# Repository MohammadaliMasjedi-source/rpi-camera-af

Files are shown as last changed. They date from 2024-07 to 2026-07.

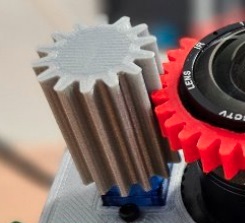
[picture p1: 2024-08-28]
Device setup/Mount the Motor gear.jpg

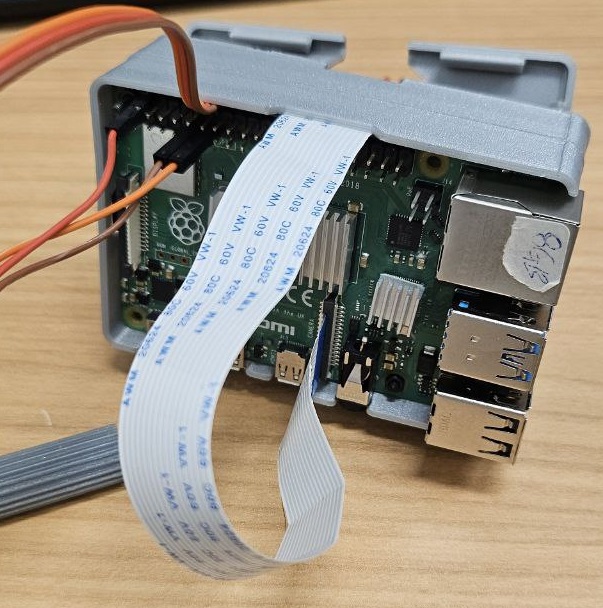
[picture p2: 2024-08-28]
Device setup/Connect the jumper wire to the desire GPIO pins.jpg

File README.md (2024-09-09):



# RPI-Camera-AF
## Auto Focus Camera using Raspberry Pi, Lens, and a Servo Motor

### Overview
The RPI-Camera-AF project leverages the versatile Raspberry Pi platform to create a modular camera system capable of automatic focusing. This innovative setup utilizes a combination of a high-quality lens, a precise servo motor, and custom 3D-printed components, orchestrated by the powerful Raspberry Pi 4 to enhance image clarity dynamically.

## Abstract
This project aimed to design and develop a modular camera platform using a Raspberry Pi, integrating various components such as a camera sensor, a wide lens, an FS90R servo motor, and 3D-printed gears. The primary objective was to create an autofocus mechanism that dynamically adjusts focus by calculating the Laplacian variance of live frame previews to achieve optimal sharpness. The methodology involved assembling the hardware components, programming the Raspberry Pi to control the servo motor based on image sharpness metrics, and enabling real-time focus adjustments. Initial tests demonstrated that while the system could effectively identify and adjust to changes in frame sharpness, limitations related to the precision of the lens's focal point, the quality of the sensor, and the accuracy of the servo motor control were identified. These factors affected the overall efficacy of the autofocus system. The project concluded that while the prototype showed potential, enhancements in hardware precision and control algorithms are necessary for practical applications. Future work will focus on refining these elements to improve system reliability and performance.

## Materials and Methods
In this project, we employed several hardware components and software tools to build our modular camera system. The core of our setup was the **Raspberry Pi 4**, a powerful model with sufficient processing capabilities for image handling and device control. This microcontroller was chosen for its robust support and the ability to interface with various peripherals via its GPIO (General Purpose Input/Output) pins.

### Hardware Components:
- **Raspberry Pi 4**: Serves as the processing unit and control hub.
- **Camera Sensor**: Connects to the Raspberry Pi via the 2-lane MIPI CSI camera port for capturing high-quality images.
- **FS90R Servo Motor**: Compact and lightweight, this motor adjusts the camera lens's focus, interfacing with the Raspberry Pi's GPIO pins.
- **3D-Printed Gears**: One gear mounted on the camera lens and the other on the servo motor to mesh perfectly and enable precise focus adjustments.

### Software Tools:
- **OpenCV (CV2)**: Used for real-time image processing, including calculating the Laplacian variance to determine image sharpness.
- **PiCamera 2 Library**: Designed for interfacing with the Raspberry Pi's camera module to capture and manipulate images directly.
- **RPi.GPIO Library**: Manages the GPIO pins for servo motor control, providing necessary instructions based on the image processing results.

### Assembly Process:
The assembly process involved carefully integrating these components. We started by connecting the camera sensor to the Raspberry Pi via the MIPI CSI port and setting up the servo motor via the GPIO pins. Next, the gears were attached—one on the lens and the other on the servo motor. We positioned the motor close enough to the lens so that the gears could engage correctly to transfer motion from the motor to the lens. This setup ensured that when the motor activated, the lens would rotate to adjust focus based on our software analysis. This methodical assembly ensured all parts worked in harmony, allowing for precise control and optimal image clarity.

## System Design and Implementation

Our modular camera system is designed to automate focusing through a manual lens using a Raspberry Pi 4 as the central controller. It features a well-coordinated assembly of hardware and software components.

### Hardware Components
- **Raspberry Pi 4**: Serves as the central processing unit, interfacing with the camera sensor via the 2-lane MIPI CSI camera port for high-quality image capture.
- **FS90R Servo Motor**: Manages autofocus by adjusting the lens position based on focus requirements, controlled through the Raspberry Pi’s GPIO pins.
- **3D-Printed Gears**: Engages between the lens and the servo motor, facilitating manual focus adjustments by translating motor movements into direct lens focus adjustments.

### Software Components
- **Python Libraries**:
  - **cv2**: Handles image processing tasks, such as calculating image sharpness.
  - **PiCamera 2**: Manages camera operations.
  - **RPi.GPIO**: Controls the GPIO pins that drive the servo motor.
  - **Threading Module**: Utilizes Python’s threading capabilities to maintain a live view from the camera while adjusting focus in real-time.

### System Operation
The system uses a Python script that integrates and controls these components effectively:
- **FrameVarianceMonitor Class**: Tracks the sharpness of consecutive images, storing variance values to determine when maximum focus is achieved.
- **Motor Control Functions (`rightmove()`, `leftmove()`)**: Adjust the motor’s direction and focus using `pwm.ChangeDutyCycle` to send signals to the servo.
- **Main Function (`moarso()`)**: Orchestrates the autofocus process by comparing sharpness values from consecutive frames and deciding the motor’s direction based on whether image sharpness is improving.

### Integration and Functionality
- **Servo Motor and Lens Integration**: The servo motor's integration with the lens via 3D-printed gears is a key aspect of our design, ensuring that each motor adjustment translates directly into lens movement.
- **Python Script Management**: Handles the complex task of focusing by continuously analyzing image quality and adjusting the lens position to ensure the camera system captures clear images and operates efficiently.
- **System Flexibility**: Designed to be robust yet adaptable, allowing for real-time adjustments and optimizations based on immediate feedback from the image processing algorithms.

### Advanced Focusing Methods
To enhance the focusing capabilities of our system, we have implemented various innovative methods, each tailored to optimize image clarity under different scenarios. These methods fully leverage the programmable features of the Raspberry Pi and our mechanical setup.

This comprehensive design and implementation ensure our camera system not only captures clear images but also maintains a balance between performance and simplicity in its operation.

## Advanced Focusing Techniques

To enhance the focusing capabilities of our camera system, we have implemented various innovative methods, each tailored to optimize image clarity under different scenarios. These methods fully leverage the programmable features of the Raspberry Pi and our mechanical setup.

### 1. Heatmap-Based Focusing
This method involves analyzing the 'heat' distribution in a frame to determine areas of highest activity or change, which often correspond to important focal points in an image. By generating a heatmap of each frame, the system identifies the 'hottest' part, which is likely to need sharper focus. This technique is particularly useful in dynamic environments, such as in wildlife photography or security applications.

### 2. Section-Based Focus
This user-driven method allows for selective focusing based on the user's input via a mouse click. When a section of the image is selected, the system focuses specifically on that area, adjusting the lens accordingly. This method is especially beneficial for controlled scenarios like macro photography or when precise depth of field control is desired. It provides the user with the flexibility to prioritize specific parts of the scene over others.

### 3. Comprehensive Frame Focusing
We explored two strategies to achieve optimal focus across the entire frame:
- **Threshold Strategy**: Sets a threshold for the number of attempts the system will make to find the frame with the highest variance—indicative of sharp focus—before stopping and capturing the image.
- **Rotational Strategy**: Involves rotating the lens in both directions multiple times to determine the optimum lens position, ensuring that the focus is refined by considering multiple positions and selecting the one that consistently provides the best clarity.

### Challenges and Refinements
One of the main challenges we encountered was the inability to achieve micro-adjustments with the motor and lens system, as the gears and motor setup did not allow for minute, millimeter-level changes. This limitation made it difficult to achieve extremely precise focus, particularly in scenarios requiring a very shallow depth of field or when dealing with micro-scale subjects. However, through iterative testing and refinement, we developed practical algorithms that approximate the best possible focus within the mechanical constraints. Once the optimal focus position is found, the system maintains that position until a significant change in the scene is detected—such as movements or lighting changes—which triggers a re-evaluation of the focus to ensure continuous clarity.

These methods collectively enhance the usability and functionality of our camera system, providing both automated and user-controllable options to achieve the desired focus, and adaptively responding to changes in the environment to maintain image quality.

[Complete device setup](https://github.com/ETCE-LAB/rpi-camera-af/blob/main/Device%20setup/Complete%20device%20setup.jpg)

[Step by step implementation guide to get the result](https://github.com/ETCE-LAB/rpi-camera-af/blob/main/Step%20by%20Step%20to%20implementation.pdf)

[Python script](https://github.com/ETCE-LAB/rpi-camera-af/blob/main/Autofocus.py)

[mountable items - 3D CAD](https://github.com/ETCE-LAB/rpi-camera-af/tree/main/mountable%20items%20-%203D%20CAD)
## Assembly Instructions

Before you start the assembly, ensure you have all the necessary tools and components listed.

### Tools Required for Assembly:
Before beginning, gather the following tools:
1. iFixit Micro Screwdriver
2. Pliers
3. Wire Cutter/Stripper
4. Double-Sided Tape

### Hardware Components:
1. **Raspberry Pi 4**: Serves as the main controller of the camera.
2. **Micro SD Card (32 GB)**: For Raspberry Pi OS and software.
3. **3D-Printed Parts**: Listed below with corresponding CAD files.
   - [Front Frame](https://github.com/ETCE-LAB/rpi-camera-af/blob/main/mountable%20items%20-%203D%20CAD/back-frame.stl)
   - [Front Cover](https://github.com/ETCE-LAB/rpi-camera-af/blob/main/mountable%20items%20-%203D%20CAD/Front-Cover-with-servo-mount.stl)
   - [Back Frame](https://github.com/ETCE-LAB/rpi-camera-af/blob/main/mountable%20items%20-%203D%20CAD/back-frame.stl)
   - [PCB Mount](https://github.com/ETCE-LAB/rpi-camera-af/blob/main/mountable%20items%20-%203D%20CAD/pcb-mount.stl)
   - [Servo Gear Module](https://github.com/ETCE-LAB/rpi-camera-af/blob/main/mountable%20items%20-%203D%20CAD/servo-gear-13T-thicker-longer.stl)
   - [Lens Gear Module](https://github.com/ETCE-LAB/rpi-camera-af/blob/main/mountable%20items%20-%203D%20CAD/Lens-Gear-modul-1.2-30T-30mm-outer-diam-extruded.stl)
5. **Jumper Cables**: Male to Male and Male to Female.
6. **Camera Module**: HQ camera v1.0 and Arducam lenses 120 degree with manual focus.
7. **Power Supply**: 5V, 2.5-3A for Raspberry Pi.
8. **Micro HDMI Cable**
9. **Servo Motor**: Feetech FS90R 360° Continuous Rotation.

### Component Installation Instructions:
1. Mount the image sensor on the PCB Mount. [Image](https://github.com/ETCE-LAB/rpi-camera-af/blob/main/Device%20setup/Mount%20the%20image%20sensor%20on%20the%20PCB-Mount.jpg) | [CAD file](https://github.com/ETCE-LAB/rpi-camera-af/blob/main/mountable%20items%20-%203D%20CAD/pcb-mount.stl)
2. Mount the ring gear on the lens using double-sided tape. [Image](https://github.com/ETCE-LAB/rpi-camera-af/blob/main/Device%20setup/Mount%20the%20ring%20gear%20on%20lens%2C%20using%20double%20side%20tape.jpg) | [CAD file](https://github.com/ETCE-LAB/rpi-camera-af/blob/main/mountable%20items%20-%203D%20CAD/Lens-Gear-modul-1.2-30T-30mm-outer-diam-extruded.stl)
3. Attach the PCB mount to the Raspberry mount. [Image](https://github.com/ETCE-LAB/rpi-camera-af/blob/main/Device%20setup/attach%20the%20PCB-mount%20to%20the%20Raspberry-mount.jpg) | [CAD file](https://github.com/ETCE-LAB/rpi-camera-af/blob/main/mountable%20items%20-%203D%20CAD/back-frame.stl)
4. Mount the Raspberry on the Raspberry mount. [Image](https://github.com/ETCE-LAB/rpi-camera-af/blob/main/Device%20setup/Mount%20the%20raspberry%20on%20the%20Raspberry-mount.jpg)
5. Connect the camera to the Camera connector on the board. [Image](https://github.com/ETCE-LAB/rpi-camera-af/blob/main/Device%20setup/Connect%20the%20camera%20to%20the%20Camera-connector%20on%20the%20board.jpg)
6. Mount the lens on the camera. [Image](https://github.com/ETCE-LAB/rpi-camera-af/blob/main/Device%20setup/Mount%20the%20lens%20on%20the%20camera.jpg)
7. Add the case extension to the Raspberry mount. [Image](https://github.com/ETCE-LAB/rpi-camera-af/blob/main/Device%20setup/Add%20the%20case%20extension%20to%20on%20the%20Raspberry%20mount.jpg) | [CAD file](https://github.com/ETCE-LAB/rpi-camera-af/blob/main/mountable%20items%20-%203D%20CAD/front-frame.stl)
8. Mount the Servo FS-90R to the front case. [Image](https://github.com/ETCE-LAB/rpi-camera-af/blob/main/Device%20setup/Mount%20the%20Servo-%20fs-90r%20to%20the%20front-case.jpg) | [CAD file](https://github.com/ETCE-LAB/rpi-camera-af/blob/main/mountable%20items%20-%203D%20CAD/Front-Cover-with-servo-mount.stl)
9. Connect the jumper wire to the desired GPIO pins. [Image](https://github.com/ETCE-LAB/rpi-camera-af/blob/main/Device%20setup/Connect%20the%20jumper%20wire%20to%20the%20desire%20GPIO%20pins.jpg)
10. Mount the Motor gear. [Image](https://github.com/ETCE-LAB/rpi-camera-af/blob/main/Device%20setup/Mount%20the%20Motor%20gear.jpg) | [CAD file](https://github.com/ETCE-LAB/rpi-camera-af/blob/main/mountable%20items%20-%203D%20CAD/servo-gear-13T-thicker-longer.stl)
11. Fix the front case lid, and secure with Cable tie-wraps. [Image](https://github.com/ETCE-LAB/rpi-camera-af/blob/main/Device%20setup/Fix%20the%20front%20case%20lid%2C%20and%20tie%20with%20Cable%20tie-wrap.jpg)

This comprehensive guide will ensure a smooth assembly process for your modular camera system.

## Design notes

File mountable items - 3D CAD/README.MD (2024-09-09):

# 3D CAD Files: Raspberry Pi Case & Mountable Gears

Welcome to our repository of 3D CAD files, designed for makers and DIY enthusiasts. Here, you'll find everything you need to 3D print a custom Raspberry Pi case, along with a selection of mountable gears for various mechanical projects.

## What's Included

- **Raspberry Pi Case Parts**: Modular pieces that let you build a sturdy, functional, and aesthetically pleasing case for your Raspberry Pi. The design facilitates easy access to ports and ensures proper ventilation.
- **Mountable Gears**: A diverse array of gears, including spur, bevel, and worm gears, perfect for your custom mechanical builds.

## How to Use

Download the STL files, load them into your 3D printer, and adhere to our basic guidelines for optimal results. The parts are designed to be straightforward to print and assemble, simplifying

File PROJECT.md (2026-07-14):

# 📷 RPi Camera Autofocus
> Camera autofocus on Raspberry Pi 4 driving an FS90R servo - Python focus algorithms, 3D-printed mounts, and a step-by-step build guide.

**Status:** shipped · **Priority:** low · **Progress:** 100% · **Private:** no
**Links:** [GitHub](https://github.com/MohammadaliMasjedi-source/rpi-camera-af) · [Dashboard](dashboard/index.html)

> Seminar / project work in the ETCE department of TU Clausthal. Companion to `.mc/project.json`.

## Vision
A complete, reproducible **autofocus rig**: a Raspberry Pi 4 turns a lens focus ring through a 3D-printed
gear driven by an FS90R servo, while a Python sharpness metric finds the in-focus position. Everything
needed to rebuild it - code, 3D-printable parts, wiring, and a photo build guide - lives in this repo.

## Phases
### Phase 1 — Mechanics + electronics  ✅ 100%
- [x] 3D-printed lens gear, servo mount, frames (`mountable items - 3D CAD/`)
- [x] Wire FS90R servo to RPi4 GPIO
- [x] Mount camera + image sensor

### Phase 2 — Focus algorithm  ✅ 100%
- [x] Sharpness metric — variance (`click_variance.py`) / heatmap (`heatmapmethod.py`)
- [x] Servo sweep + peak-focus search (`Autofocus.py`)

### Phase 3 — Documentation  ✅ 100%
- [x] Step-by-step build guide (`Step by Step to implementation.pdf` + `Device setup/` photos)
- [x] README + `Script description.txt`

## Approach
`Autofocus.py` sweeps the FS90R servo across the focus range and scores each frame's sharpness; the
position with the highest score is selected. Two sharpness metrics are provided: a pixel-variance
method and a heatmap method. Mechanical parts are parametric STLs printable on a standard FDM printer.

## Hardware
- Raspberry Pi 4 + Pi camera
- FS90R continuous-rotation micro servo
- 3D-printed: lens gear (module 1.2, 30T), servo gear (13T), front cover with servo mount, frames, PCB mount

## Decisions (log)
| Date | Decision | Why | Rejected |
|---|---|-----|---|
| 2024-09-09 | Variance/heatmap sharpness metric | Simple, fast, robust on-device | FFT-based sharpness |

## SWOT
- **Strengths** — complete reproducible build; documented end to end; low-cost parts.
- **Weaknesses** — FS90R is continuous-rotation (open-loop positioning); single lens tested.
- **Opportunities** — closed-loop with an encoder; reuse the focus metric on other rigs.
- **Threats** — tied to a specific RPi camera stack.

## Build it
See `docs/BUILD.md`, the photos in `Device setup/`, and `Step by Step to implementation.pdf`.

## ✅ Definition of Done (certified 2026-07-14)
**DONE** — a *documented, working hardware prototype*. "Done" here means the rig can be rebuilt
from this repo alone:
- **Autofocus code present + syntax-valid** — `Autofocus.py` uses Laplacian-variance sharpness
  (`is_blurred()` → `cv2.Laplacian(...).var()`), FS90R servo control (`rightmove()` / `leftmove()`
  via PWM duty cycle), and a threaded live-preview + peak-focus sweep. Plus `click_variance.py`
  (variance) and `heatmapmethod.py` (heatmap) focus metrics. All three parse clean.
- **Hardware fully documented** — all 7 CAD STLs in `mountable items - 3D CAD/`, every wiring/
  assembly photo in `Device setup/`, and `docs/BUILD.md` + `Step by Step to implementation.pdf`
  cover print → assemble → wire → run end to end.
- **Limitations noted honestly** — FS90R is continuous-rotation ⇒ open-loop, no micro-adjustment;
  single lens/camera tested; tied to the RPi PiCamera2 stack; the script needs real RPi4 + camera
  + servo hardware to execute.

*Note:* the README hyperlinks point at the upstream `ETCE-LAB` repo, but every file they reference
also lives here, so this repo is self-contained and reproducible.

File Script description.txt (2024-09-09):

Script Description

This code sets up a Raspberry Pi to work with its camera and manage tasks related to image handling and controlling physical components. Here's what each part does:

time: Used for tasks that involve timing, such as delays.
cv2 (OpenCV): Helps the Raspberry Pi work with images and videos.
picamera2: A specialized tool for using the Raspberry Pi's camera.
RPi.GPIO: Allows the Raspberry Pi to control external devices connected to its pins.
threading: Helps run different tasks simultaneously without interference.
queue: Used for organizing data that the Raspberry Pi needs to handle sequentially.
numpy: Aids with calculations and organizing data, especially for images.
collections.deque: Helps manage data that changes frequently.
datetime: Used for anything that requires the date and time, such as adding timestamps to photos.
This setup is mainly for projects that need to capture and process images, manage timing, and interact with devices connected to the Raspberry Pi.

import time
import cv2
from picamera2 import Picamera2
import RPi.GPIO as GPIO
import threading
import queue
import numpy
from collections import deque
from datetime import datetime

This class is designed to track the variance of the last 30 numerical values it receives. It continuously updates as new values come in, ensuring that the variance calculation remains relevant to the most recent 30 values. This feature is useful for monitoring changes in data over time, particularly when it's important to understand how much the values vary within a fixed window size.

class FrameVarianceMonitor:
def __init__(self, window_size):
self.window_size = window_size
self.variances = deque(maxlen=window_size)
self.current_max = float('-inf')
Page 9 of 19def add_variance(self, variance):
if variance>11:
self.variances.append(variance)
if len(self.variances) == self.window_size:
self.current_max = max(self.variances)
else:
if variance > self.current_max:
self.current_max = variance
def get_max_variance(self):
return self.current_max
def is_maximum_found(self):
if len(self.variances) == self.window_size and self.current_max in
self.variances:
self.clear_variances()
return True
return False
def clear_variances(self):
self.variances.clear()
self.current_max = float('-inf')
window_size = 30
monitor = FrameVarianceMonitor(window_size)

This code snippet sets up a Raspberry Pi to control a servo motor and start a camera for video capture:

Servo Motor Setup:

servo_pin = 11: Assigns pin 11 to control the servo motor.
GPIO.setmode(GPIO.BOARD): Configures the GPIO pins by their physical locations on the board.
GPIO.setup(servo_pin, GPIO.OUT): Sets the servo pin as an output.
pwm = GPIO.PWM(servo_pin, 50): Initializes PWM (Pulse Width Modulation) on the servo pin at 50 Hz, used to control the servo's angle.
pwm.start(0): Begins sending a PWM signal with a duty cycle of 0%, positioning the servo at its starting position.
Camera Setup:

picam2 = Picamera2(): Creates a new instance of Picamera2, a tool for controlling the Raspberry Pi Camera Module.
video_config = picam2.create_video_configuration(main={"size": (480,360)}): Configures the camera to capture video at a resolution of 480x360 pixels.

size_tuple = video_config['main']['size']: Extracts the resolution as a tuple (480, 360).
size_str = str(size_tuple): Converts the resolution tuple to a string, possibly for logging
or display purposes.
picam2.configure(video_config): Applies the video configuration to the camera.
picam2.start(): Starts the camera, beginning video capture at the specified
resolution.
Overall, this code prepares the Raspberry Pi to manipulate a servo motor and continuously
capture video, integrating hardware control with video processing.

servo_pin = 11
GPIO.setmode(GPIO.BOARD)
GPIO.setup(servo_pin, GPIO.OUT)
pwm = GPIO.PWM(servo_pin, 50)
pwm.start(0)
picam2 = Picamera2()
video_config = picam2.create_video_configuration(main={"size": (480,360)})
size_tuple = video_config['main']['size']
size_str = str(size_tuple)
picam2.configure(video_config)
picam2.start()

This function, is_blurred, checks if an image is blurred by converting it to grayscale and calculating the variance of the Laplacian, which measures the image's second derivatives. A low variance indicates less edge detail, suggesting the image might be blurred. The function returns the variance as an integer, which can be used to determine the level of blurriness.

def is_blurred(img):
gray = cv2.cvtColor(img, cv2.COLOR_BGR2GRAY)
lap_var = cv2.Laplacian(gray, cv2.CV_64F).var()
return int(lap_var)

The function compare examines two numbers, a and b, and determines if they are equal, if one is greater, or if one is less. It uses a very small number called tolerance to decide if the numbers are close enough to be considered equal, accommodating minor differences that often occur with decimal numbers in computing. This small tolerance is used to enhance precision in comparisons, especially important in situations involving very precise measurements or calculations. If a and b are within this tolerance, the function considers them "equal." If not, it checks if a is greater than b to determine if it should return "greater," or else it returns "less."

def compare (a,b,tol=1e-15):
if abs(a-b)<tol:
return "equal"
return "greater" if a>b else "less"

The provided code consists of two functions, rightmove and leftmove, which control a servo motor's movement to the right and left, respectively, using PWM (Pulse Width Modulation):

rightmove(): This function sets the PWM duty cycle to 12 to move the servo to the right. It holds this position for 0.02 seconds, then stops the PWM signal (sets it to 0) and waits for 0.3 seconds to stabilize the servo in its new position.

leftmove(): Similarly, this function sets the PWM duty cycle to 1 to move the servo to the left, holds it for 0.02 seconds, then stops the PWM and waits for 0.3 seconds.

These functions are typically used in robotic applications where precise, timed movements of a servo motor are required.

def rightmove():
pwm.ChangeDutyCycle(12)
time.sleep(0.02)
pwm.ChangeDutyCycle(0)
time.sleep(0.3)

def leftmove():
pwm.ChangeDutyCycle(1)
time.sleep(0.02)
pwm.ChangeDutyCycle(0)
time.sleep(0.3)

The script provided contains two functions, frameshow and show, which work together to display a live video stream from a camera using OpenCV:

frameshow(picam2): This function takes a picam2 camera object as an argument. It captures an image array from the camera. If no frame is captured (frame is None), it returns True, indicating an issue, but continues. Otherwise, it converts the color format of the frame from RGB to BGR (which is the color format OpenCV uses for images). It then creates and displays the frame in a fullscreen window named 'Frame'. If the user presses the 'q' key, the function returns False, signaling to stop the video stream.

show(): This is a loop function that continuously calls frameshow. As long as frameshow returns True, it keeps running, showing new frames from the camera. If frameshow returns False (when the 'q' key is pressed), the loop breaks, effectively ending the video stream display.

This setup is typically used in applications where live video feedback is required, such as in security systems, monitoring systems, or interactive projects. The use of a loop in show ensures continuous frame updates, and the condition inside allows for a graceful shutdown on a key press.

def frameshow(picam2):
frame = picam2.capture_array()
if frame is None:
#print("Failed to capture image")
return True
frame = cv2.cvtColor(frame, cv2.COLOR_RGB2BGR)
cv2.namedWindow('Frame', cv2.WINDOW_NORMAL)
cv2.setWindowProperty('Frame', cv2.WND_PROP_FULLSCREEN,
cv2.WINDOW_FULLSCREEN)
cv2.imshow('Frame', frame)
if cv2.waitKey(1) & 0xFF == ord('q'):
return False
return True

def show():
while True:
if not frameshow(picam2):
break

The function takepic(x, y) takes two parameters, x and y, and uses them to capture a picture with a Raspberry Pi camera, tagging it with metadata in the filename. It first captures the current date and time, formats it as "YYYYMMDD_HHMMSS", and then constructs a filename that includes this timestamp, the variance (x), and the resolution (y). The photo is saved with this filename as a JPEG file. If you need to capture a video instead of a picture, you could modify the function to use the camera's video recording capabilities in place of the image capture command.

def takepic(x,y):
now = datetime.now()
filename = now.strftime("%Y%m%d_%H%M%S")
picam2.capture_file(f"{filename}_variance_is_{x}_resolution_is_{y}.jpg")

The code controls a camera lens to optimize the focus by adjusting its rotation and monitoring the variance in the video frame in real time. Here’s how it works:

Direction Setting and Monitoring: The lens can rotate left or right, a direction you can set in the code. As the lens rotates, the code calculates the frame's variance to determine image sharpness.

Adjusting Rotation Based on Variance: If the variance (sharpness) increases, the rotation direction is correct. If it decreases, indicating a loss in focus, the code reverses the rotation direction to find a better focus.

Handling Over-rotation: Since the motor control isn't precise, it might overshoot the point of maximum variance. If this happens, the lens may oscillate around this optimal focus point. The code is designed to detect if the motor has changed direction five times consecutively, interpreting this as having achieved the best possible focus within operational limits, and then stops the motor.

Continuous Monitoring and Re-adjustment: Even after stopping, the system continues to monitor the variance. If it changes by 10% (either increases or decreases), this signals a significant shift in focus quality, prompting the system to restart the process of seeking the area with the highest variance to adjust the focus again.

This setup is particularly useful for applications where continuous and automatic focus adjustment is necessary, such as in surveillance or automated photography environments.

def moarso():
initial_var=is_blurred(picam2.capture_array())
leftmove()
second_var=is_blurred(picam2.capture_array())
comp_res=compare(second_var,initial_var)
# either use "rotate=False" or below if condition for better readability
if comp_res=="greater" or comp_res=="equal":
rotate=False #false means rotation direction is left
else:
rotate=True #true means rotation direction is right
#print("initial_var",initial_var,"second_var",second_var)
try:
start_time = time.time()
count=0
while True:
# monitor.add_variance(is_blurred(picam2.capture_array()))
Page 14 of 19# if monitor.is_maximum_found():
# current_max = monitor.get_max_variance()
# #print(f"Maximum variance in the last {window_size} frames:
{current_max}")
# picvar=is_blurred(picam2.capture_array())
# takepic(picvar)
# realtimevar=picvar
# while (picvar*0.9<=realtimevar<=picvar*1.1):
# realtimevar=is_blurred(picam2.capture_array())
if rotate==True:
rightmove()
initial_var=second_var
second_var=is_blurred(picam2.capture_array())
print("if rotate==True: , second_var:
",second_var,"
initial_var: ",initial_var)
comp_res=compare(second_var,initial_var)
if comp_res=="greater" or comp_res=="equal":
rotate=True
else:
rotate=False
count+=1
if rotate==False:
leftmove()
initial_var=second_var
second_var=is_blurred(picam2.capture_array())
print("if rotate==False: , second_var:
",second_var,"
initial_var:",initial_var)
comp_res=compare(second_var,initial_var)
if comp_res=="greater" or comp_res=="equal":
rotate=False
else:
rotate=True
count+=1
if count>5:
picvar=is_blurred(picam2.capture_array())
takepic(picvar,size_str)
realtimevar=picvar
count=0
end_time = time.time()
runtime = end_time - start_time
print(f"The runtime of the code is {runtime} seconds.")
print("change now")
while (picvar*0.9<=realtimevar<=picvar*1.1):
realtimevar=is_blurred(picam2.capture_array())
time.sleep(5)
Page 15 of 19start_time = time.time()
#print(f"count is {count}")
except KeyboardInterrupt:
print("Interrupted by user.")
finally:
pwm.stop()
GPIO.cleanup()
picam2.stop()
picam2.close()
cv2.destroyAllWindows()

The provided code snippet initiates two separate threads using Python's threading module, aimed at handling autofocus and live video display simultaneously:

Initialization of Threads:

focus_thread = threading.Thread(target=moarso): This thread is dedicated to the autofocus function, which presumably adjusts the focus of a camera lens. The target function moarso suggests a method for calculating and adjusting focus automatically.
frameshow_thread = threading.Thread(target=show): This thread is responsible for displaying the live video feed from the camera. The target function show handles the continual capture and display of video frames.
Starting the Threads:

focus_thread.start(): Activates the autofocus thread, allowing it to run independently.
frameshow_thread.start(): Starts the live video display thread simultaneously.
Benefits of Using Threading in this Context:

Uninterrupted Live View: By separating the video display and autofocus calculations into different threads, the live video can remain smooth and uninterrupted. This is because the demanding autofocus calculations are being handled in parallel, rather than sequentially which could block the video feed and cause delays or stuttering.

Improved Responsiveness: Each thread operates independently, so the user interface, likely the video feed, remains responsive and fluid even as complex autofocus adjustments are being made in the background.

Efficiency: Threading can make better use of the processor's capabilities by distributing tasks across multiple cores where available, speeding up the overall process of autofocus while maintaining real-time video output.

Synchronization and Flexibility: Separate threads allow for more flexible program design, where different tasks can be paused, stopped, or prioritized without affecting others. This is particularly useful in dynamic environments like live video feeds where conditions change rapidly.

Overall, using threading in this manner optimizes the camera's functionality for scenarios like surveillance, live streaming, or any application requiring both continuous video capture and dynamic focus adjustment.

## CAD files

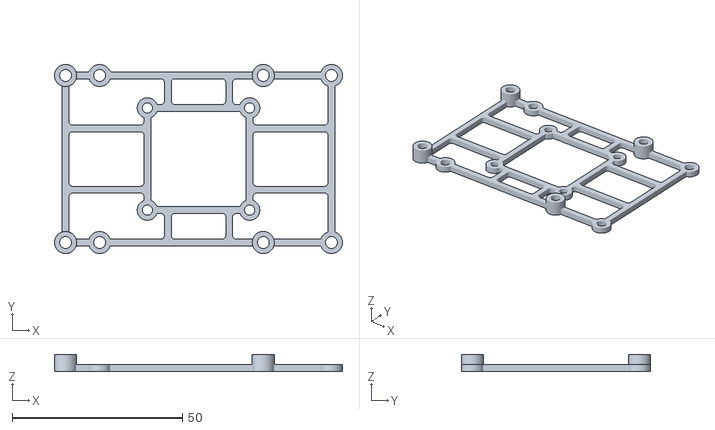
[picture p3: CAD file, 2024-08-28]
mountable items - 3D CAD/pcb-mount.stl
84.5 x 55.5 x 5.00

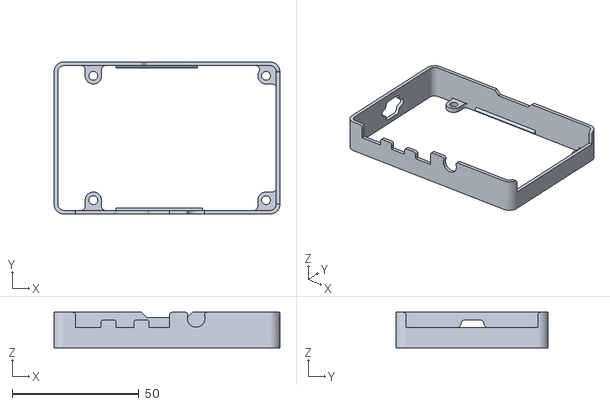
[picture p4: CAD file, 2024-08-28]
mountable items - 3D CAD/back-frame.stl
89.0 x 60.0 x 14.0

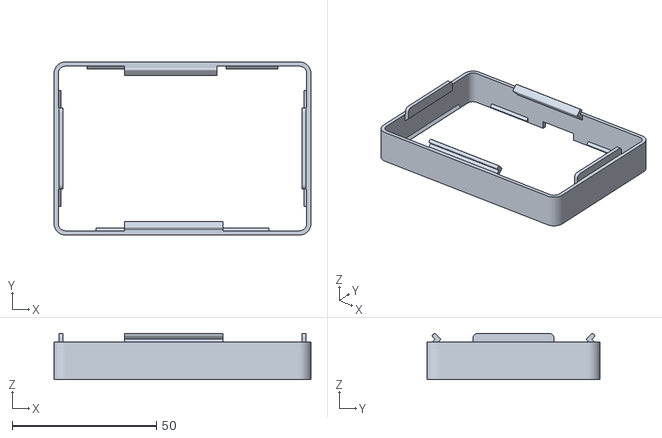
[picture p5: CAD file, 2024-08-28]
mountable items - 3D CAD/front-frame.stl
89.0 x 60.0 x 16.0

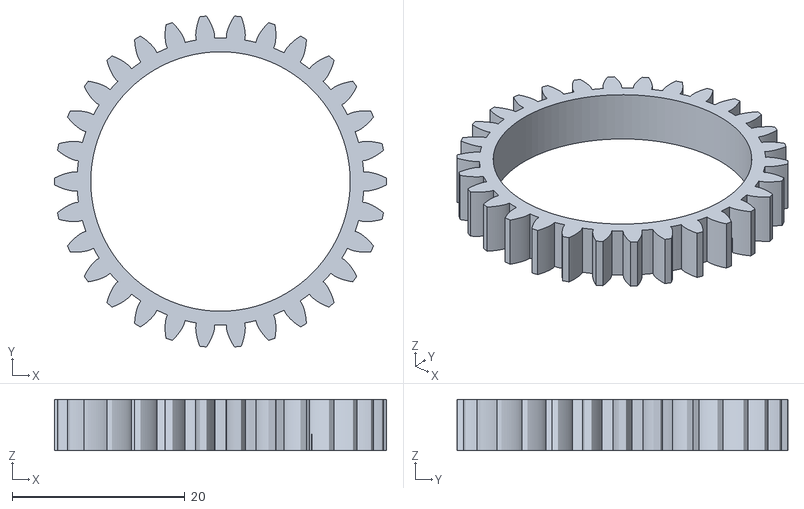
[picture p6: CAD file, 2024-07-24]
mountable items - 3D CAD/Lens-Gear-modul-1.2-30T-30mm-outer-diam-extruded.stl
38.4 x 38.3 x 5.92

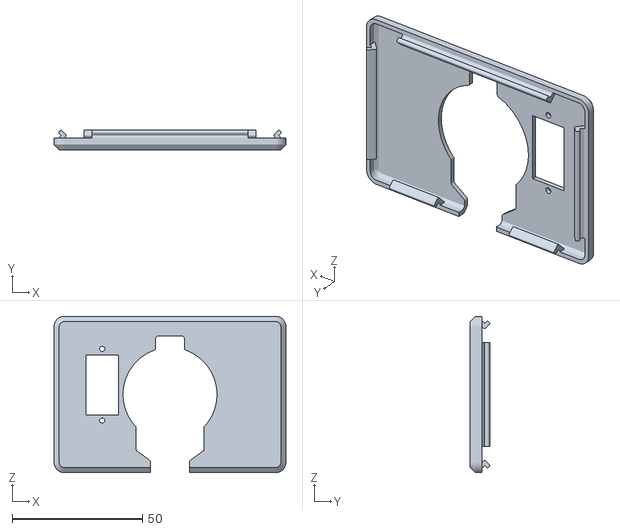
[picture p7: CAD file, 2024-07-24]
mountable items - 3D CAD/Front-Cover-with-servo-mount.stl
89.0 x 7.49 x 60.0

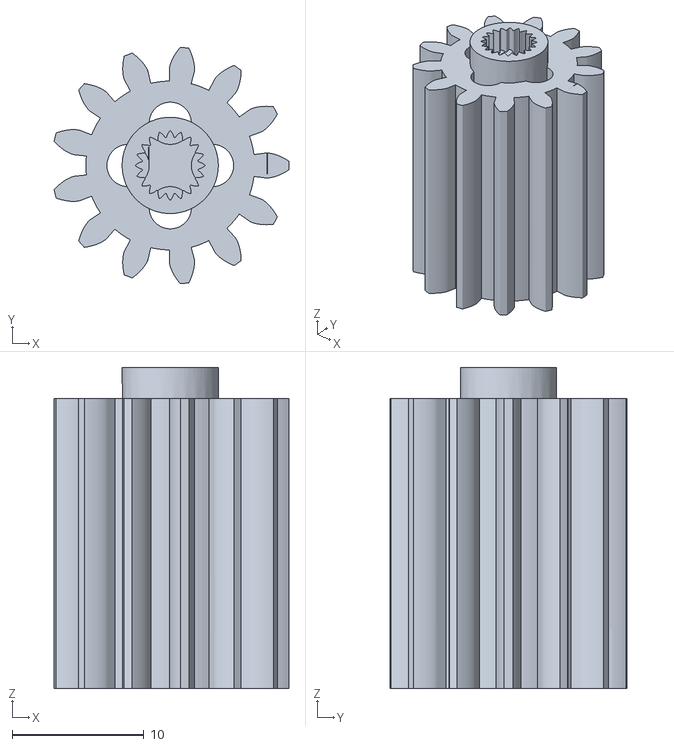
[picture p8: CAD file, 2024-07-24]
mountable items - 3D CAD/servo-gear-13T-thicker-longer.stl
17.8 x 17.9 x 24.3

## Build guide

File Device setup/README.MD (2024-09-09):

## Overview

We have constructed an advanced module using the **Raspberry Pi 4** as the core processing unit. Attached to it is an **FS90 servo motor**, which offers precise movement and positioning capabilities essential for our project's requirements.

Additionally, we have integrated an image sensor capable of capturing high-quality visuals, further enhanced by a **wide-angle lens** to broaden the field of view and capture more of the surroundings in a single frame.

To house and mount these components effectively, we designed and **3D-printed a custom mounting object**. This mount not only secures the components firmly but also aligns them perfectly to ensure optimal performance of the imaging system.

This setup is particularly useful for applications requiring detailed visual data over a wide area, such as in robotics, surveillance, and automated monitoring systems.

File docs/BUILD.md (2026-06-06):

# Build guide

A condensed index of the build. For the full walkthrough see
`Step by Step to implementation.pdf` and the photos in `Device setup/`.

## 1. Print the parts (`mountable items - 3D CAD/`)
- `Lens-Gear-modul-1.2-30T-30mm-outer-diam-extruded.stl` — gear that clamps to the lens focus ring
- `servo-gear-13T-thicker-longer.stl` — gear on the FS90R servo
- `Front-Cover-with-servo-mount.stl`, `front-frame.stl`, `back-frame.stl` — housing
- `pcb-mount.stl` — image-sensor / PCB mount

## 2. Assemble
1. Mount the lens on the camera; mount the image sensor on the PCB mount.
2. Attach the PCB mount to the Raspberry Pi mount.
3. Mount the FS90R servo to the front case; fit the servo gear.
4. Mount the lens-ring gear with double-sided tape so it meshes with the servo gear.
5. Mount the Raspberry Pi; close and cable-tie the front case.

*(Each step has a photo in `Device setup/`.)*

## 3. Wire it
Connect the FS90R servo signal to the GPIO pin shown in `Device setup/RPI used pins.jpg`
(power and ground to the Pi's 5V/GND rails).

## 4. Run autofocus
```bash
python3 Autofocus.py
```
The script sweeps the servo across the focus range, scores each frame's sharpness, and parks at the
sharpest position.

## Focus metrics
| Script | Method |
|---|---|
| `click_variance.py` | Pixel-intensity **variance** as the sharpness score |
| `heatmapmethod.py`  | **Heatmap** based sharpness evaluation |
| `Autofocus.py` | Drives the servo sweep and selects peak focus |

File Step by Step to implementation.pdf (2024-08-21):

### 1. Hardware Setup

To begin, ensure you have the following hardware components:

- Raspberry Pi: Any model that supports GPIO pins and can run the latest version of Raspberry Pi OS.
- Camera Module: A PiCamera module is necessary for image capturing.
- Servo Motor: Used for moving the camera to adjust focus.
- Breadboard and jumper wires: For connecting the servo motor to the Raspberry Pi.
- Power Supply: Suitable for the Raspberry Pi and peripherals.

Connections:

- Connect the camera module to the CSI port of the Raspberry Pi.
- Connect the servo motor to one of the GPIO pins (e.g., GPIO 11 as mentioned in your script).

### 2. Software Setup

Before running the script, you’ll need to install various software components and libraries:

Operating System:

- Install Raspberry Pi OS: Download the latest version from the Raspberry Pi website and flash it onto an SD card using software like Raspberry Pi Imager.

Python and Libraries:

- Python: Ensure Python is installed. Raspberry Pi OS typically comes with Python pre-installed.
- OpenCV and PiCamera: You will need OpenCV for image processing and the picamera2 library for controlling the PiCamera module.

bash
Copy code
sudo apt update
sudo apt install python3-opencv pip3 install picamera2

GPIO Library:

- RPi.GPIO: This is used to control GPIO pins. It's often pre-installed, but you can reinstall or update it:

bash
Copy code
pip3 install RPi.GPIO

### 3. Enable Interfaces

Through the Raspberry Pi Configuration settings:

- Enable Camera: Go to Preferences > Raspberry Pi Configuration > Interfaces, and enable the camera.
- Enable SSH (optional): If you need remote access to the Raspberry Pi.

### 4. Testing Hardware:

- Test the Camera: Check if the camera is working with a simple capture test using the

picamera2 library.
- Test the Servo Motor: Run a basic script to see if the servo reacts correctly.

### 5. Code Deployment

- Transfer Your Script: Use SCP or a USB drive to transfer your script to the Raspberry Pi.
- Run the Script: Navigate to the directory containing your script and run it with Python3.

bash
Copy code
python3 your_script_name.py

### 6. Troubleshooting

- Ensure all connections are secure.
- Check the terminal output for any error messages that can help in diagnosing issues with the script or hardware.

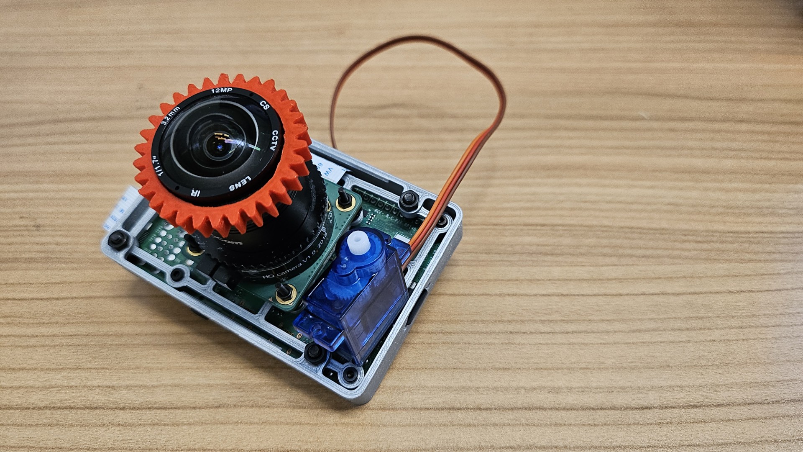
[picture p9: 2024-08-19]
Device setup/front view.jpg

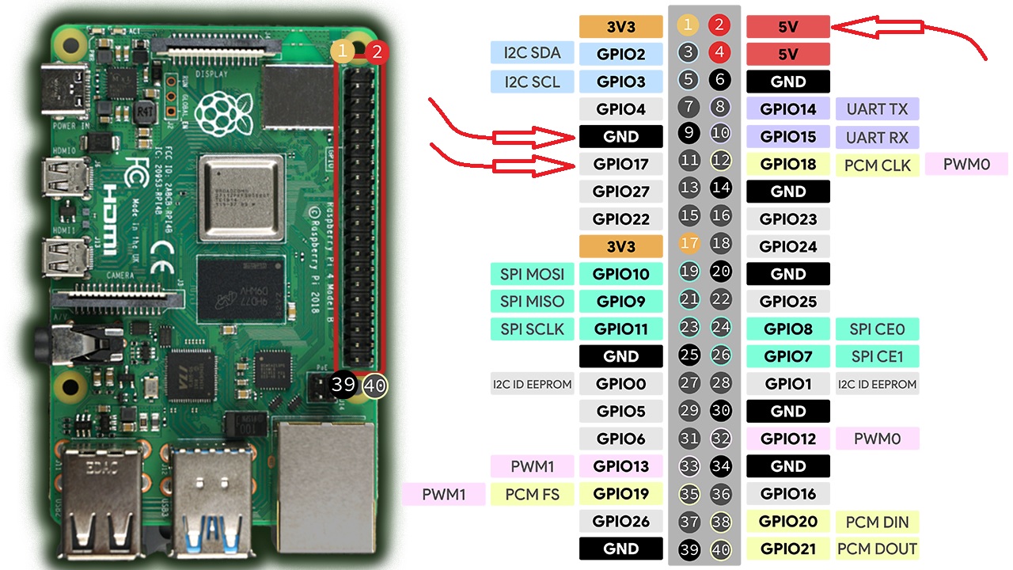
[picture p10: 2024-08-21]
Device setup/RPI used pins.jpg

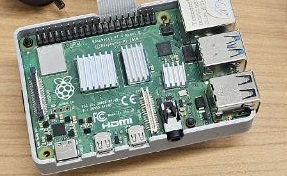
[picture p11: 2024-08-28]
Device setup/Mount the raspberry on the Raspberry-mount.jpg

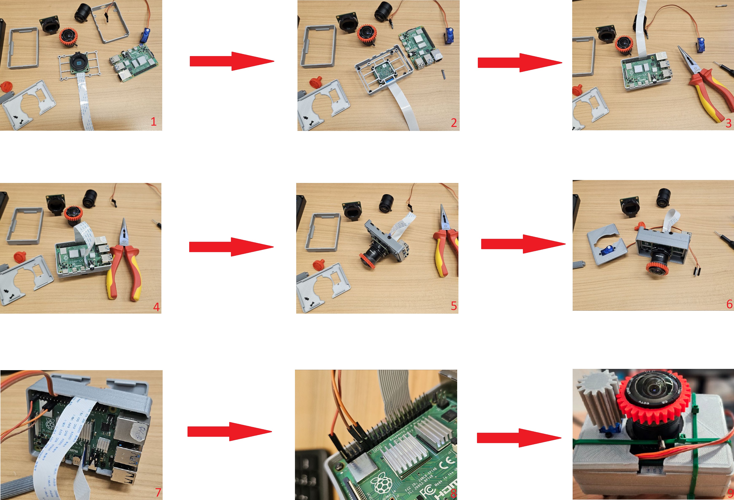
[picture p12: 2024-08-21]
Device setup/Complete device setup.jpg

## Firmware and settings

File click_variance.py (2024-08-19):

import cv2
import numpy as np
from picamera2 import Picamera2, Preview

def calculate_laplacian_variance(image, center, radius):
    # Create a mask with the same dimensions as the image, with a filled circle at the click location
    mask = np.zeros_like(image, dtype=np.uint8)
    cv2.circle(mask, center, radius, (255, 255, 255), thickness=-1)

    # Apply the mask to the image
    masked_image = cv2.bitwise_and(image, mask)

    # Convert masked image to grayscale
    gray_image = cv2.cvtColor(masked_image, cv2.COLOR_BGR2GRAY)

    # Calculate the Laplacian
    laplacian = cv2.Laplacian(gray_image, cv2.CV_64F)
    variance = laplacian.var()

    return variance

def mouse_callback(event, x, y, flags, param):
    if event == cv2.EVENT_LBUTTONDOWN:
        # Calculate the Laplacian variance for the circle with the center at (x, y) and radius 50
        frame = param['frame']
        variance = calculate_laplacian_variance(frame, (x, y), 50)
        print(f'Laplacian Variance at ({x}, {y}): {variance}')

def main():
    # Initialize the camera
    picam2 = Picamera2()

    # Configure the camera with 600x600 resolution
    camera_config = picam2.create_preview_configuration(main={"size": (600, 600)})
    picam2.configure(camera_config)

    # Start the camera
    picam2.start()

    try:
        cv2.namedWindow('Live View')
        frame = None

        while True:
            # Capture frame-by-frame
            frame = picam2.capture_array()

            # Convert to RGB color
            rgb_frame = cv2.cvtColor(frame, cv2.COLOR_BGR2RGB)

            # Display the resulting frame
            cv2.imshow('Live View', rgb_frame)

            # Set mouse callback function with the current frame
            cv2.setMouseCallback('Live View', mouse_callback, param={'frame': rgb_frame})

            # Break the loop on 'q' key press
            if cv2.waitKey(1) & 0xFF == ord('q'):
                break
    finally:
        # When everything done, release the capture
        picam2.stop()
        cv2.destroyAllWindows()

if __name__ == "__main__":
    main()

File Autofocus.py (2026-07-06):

import time
import cv2
from picamera2 import Picamera2
import RPi.GPIO as GPIO
import threading
import queue
import numpy
from collections import deque
from datetime import datetime

class FrameVarianceMonitor:
	# Initialize the monitor with a specific window size.
	def __init__(self, window_size):
		self.window_size = window_size			# Size of the sliding window for variance values
		self.variances = deque(maxlen=window_size)	# Fixed-size deque to store the latest variances
		self.current_max = float('-inf')		# Initialize the maximum variance found as negative infinity
	# Add a variance value to the deque and update the maximum variance if necessary.
	def add_variance(self, variance):
		if variance>11:
			self.variances.append(variance)
		if len(self.variances) == self.window_size:	# When window is full
			self.current_max = max(self.variances)	# Update the maximum variance over the current window
		else:
			if variance > self.current_max:		# Check if the new variance is greater than the current max
				self.current_max = variance	# Update the maximum variance
	# Return the maximum variance found in the current window.
	def get_max_variance(self):
		return self.current_max
	# Check if the maximum variance value is in the current window and reset if true.
	def is_maximum_found(self):
		if len(self.variances) == self.window_size and self.current_max in self.variances:
			self.clear_variances()			# Reset the variances deque
			return True
		return False
	# Clear all stored variances and reset the maximum variance.
	def clear_variances(self):
		self.variances.clear()
		self.current_max = float('-inf')		# Reset the maximum variance to negative infinity

window_size = 30						# Set the window size for the variance monitor
monitor = FrameVarianceMonitor(window_size)			# Create an instance of FrameVarianceMonitor with the specified window size

servo_pin = 11 							# Define the GPIO pin number that will control the servo
GPIO.setmode(GPIO.BOARD)					# Set the GPIO pin numbering to 'BOARD' style
GPIO.setup(servo_pin, GPIO.OUT)					# Set up the servo pin as an output pin
pwm = GPIO.PWM(servo_pin, 50)					# Initialize PWM on the servo pin with a frequency of 50 Hz
pwm.start(0)							# Start PWM with 0% duty cycle (servo in neutral position)
picam2 = Picamera2()						# Initialize the camera object for the Raspberry Pi
video_config = picam2.create_video_configuration(main={"size": (480,360)})# Create a video configuration with a resolution of 480x360 pixels
size_tuple = video_config['main']['size']			# Extract the size from the video configuration to a tuple
size_str = str(size_tuple)					# Convert the size tuple to a string format
picam2.configure(video_config)					# Apply the video configuration to the camera
picam2.start()							# Start the camera to begin capturing video

# Calculate frame variance
def is_blurred(img):
	gray = cv2.cvtColor(img, cv2.COLOR_BGR2GRAY)		# Convert the input image to grayscale for processing
	lap_var = cv2.Laplacian(gray, cv2.CV_64F).var()  	# Apply the Laplacian operator to detect edges and calculate the variance of the result
	return int(lap_var)					# Return the variance as an integer, A lower variance indicates less edges, suggesting the image might be blurred

# set rotation to true
rotate=True
# precise comparison in decimal
def compare (a,b,tol=1e-15):
	if abs(a-b)<tol:
		return "equal"
	return "greater" if a>b else "less"
# Servo motor right rotation
def rightmove():
	pwm.ChangeDutyCycle(12)    				# Set the PWM duty cycle to 12% to rotate the servo to the right
	time.sleep(0.02)
	pwm.ChangeDutyCycle(0)    				# Reset the PWM duty cycle to 0% to stop the servo
	time.sleep(0.3)
# Servo motor left rotation
def leftmove():
	pwm.ChangeDutyCycle(1)					# Set the PWM duty cycle to 1% to rotate the servo to the right
	time.sleep(0.02)
	pwm.ChangeDutyCycle(0)    				# Reset the PWM duty cycle to 0% to stop the servo
	time.sleep(0.3)

def frameshow(picam2):
	frame = picam2.capture_array()    			# Capture a single frame as a numpy array from the camera
	if frame is None:    					# Check if frame capture failed (i.e., returned None)
		#print("Failed to capture image")
		return True
	frame = cv2.cvtColor(frame, cv2.COLOR_RGB2BGR)    	# Convert the frame color from RGB (used by PiCamera) to BGR (used by OpenCV)
	cv2.namedWindow('Frame', cv2.WINDOW_NORMAL)   		# Create a window named 'Frame' for displaying the image
	cv2.setWindowProperty('Frame', cv2.WND_PROP_FULLSCREEN, cv2.WINDOW_FULLSCREEN)    # Set the window to full-screen mode
	cv2.imshow('Frame', frame)    				# Display the image in the 'Frame' window
	if cv2.waitKey(1) & 0xFF == ord('q'):    		# Wait for 1 millisecond and check if the 'q' key is pressed

		return False
	return True

def show():
	while True:
			if not frameshow(picam2):		# Call the frameshow function with the picam2 object, Check the return value of the frameshow function
				break

def takepic(x,y):
	now = datetime.now()    				# Get the current date and time
	filename = now.strftime("%Y%m%d_%H%M%S")   		# Format the timestamp into a string suitable for a filename
	metadata = picam2.capture_file(f"{filename}_variance_is_{x}_resolution_is_{y}.jpg")# Capture an image file with the camera. The filename includes the current timestamp, the variance value (x), and the resolution value (y). The filename is structured as: "YYYYMMDD_HHMMSS_variance_is_X_resolution_is_Y.jpg"
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

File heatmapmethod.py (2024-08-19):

import cv2
import numpy as np
from picamera2 import Picamera2

def calculate_laplacian_variance(image):
    # Apply Laplacian operator in the datatype of int16 to avoid overflow
    laplacian = cv2.Laplacian(image, cv2.CV_16S, ksize=3)
    laplacian = np.float32(laplacian)  # Convert to float for variance computation
    
    # Compute variance of Laplacian
    variance = cv2.blur(np.square(laplacian), (10, 10))  # Square of Laplacian values to find variance
    variance = variance / 100  # Normalize values for better visualization
    
    # Convert variance to heatmap
    heatmap = cv2.applyColorMap(np.uint8(variance), cv2.COLORMAP_JET)
    return heatmap

# Initialize Picamera2
picam2 = Picamera2()
preview_config = picam2.create_preview_configuration()
picam2.configure(preview_config)
picam2.start()

# Prepare windows for displaying the frames and heatmap
cv2.namedWindow("Live Camera Feed", cv2.WINDOW_AUTOSIZE)
cv2.namedWindow("Laplacian Variance Heatmap", cv2.WINDOW_AUTOSIZE)

try:
    while True:
        frame = picam2.capture_array()
        frame = cv2.cvtColor(frame, cv2.COLOR_BGR2RGB)  # Convert BGR to RGB

        # Display the live camera feed
        cv2.imshow("Live Camera Feed", frame)

        # Calculate and display the heatmap of Laplacian variance
        heatmap = calculate_laplacian_variance(frame)
        cv2.imshow("Laplacian Variance Heatmap", heatmap)

        # Exit loop when 'q' is pressed
        if cv2.waitKey(1) & 0xFF == ord('q'):
            break
except KeyboardInterrupt:
    pass
finally:
    picam2.stop()
    cv2.destroyAllWindows()

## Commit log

2024-07-16 seminar_rpi-camera-af repository
2024-08-19 move Prototype.png to Device setup/Prototype.png
2024-08-28 Necessary tools for assembly and complete hardware list added
2026-07-06 fix: correct Autofocus.py indentation TabError, CITATION.cff license, add requirements.txt
    - Autofocus.py: fixed mixed tabs/spaces on add_variance() that raised a
    TabError under python3 -m py_compile / ast.parse
    - CITATION.cff: license field now matches the repo's actual GPL-3.0 LICENSE
    - requirements.txt: lists the third-party packages imported by the scripts
    (opencv-python, numpy, picamera2, RPi.GPIO)
    [Autofocus.py]
2026-07-14 dod: certify DONE in PROJECT.md - documented working hardware prototype, limitations honest
